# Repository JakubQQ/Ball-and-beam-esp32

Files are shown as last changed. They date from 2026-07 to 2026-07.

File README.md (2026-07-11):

# ESP32 Ball and Beam Control System

An autonomous ball-and-beam stabilization system designed, manufactured, and programmed completely from scratch. This project demonstrates the practical application of control theory, embedded systems programming, and rapid prototyping.

## Key Features
- **Control Feedback Loop:** Implemented a tuned **PID controller** for real-time ball position stabilization.
- **Signal Processing:** Integrated an **EMA (Exponential Moving Average) filter** to denoise the distance sensor data without introducing critical phase lag.
- **Hardware Platform:** Powered by a **ESP32** microcontroller driving a high-torque servo motor.
- **Mechanical Design:** Custom structural components designed from scratch in **Autodesk Inventor** and manufactured via 3D printing.

## 🛠️ Engineering Challenges & Solutions

### 1. Optical Sensing Geometry
The Time-of-Flight (ToF) laser sensor features a conical field of view. During initial testing, this led to signal loss and false readings. 
* **Solution:** Iteratively optimized the sensor's mounting angle, extended the physical length of the beam, and adjusted the ball diameter to maximize the reflected light returning to the receiver.

### 2. Sensor Noise Filtering
Raw data from the ToF sensor suffered from high-frequency noise, which caused the servo to jitter and destabilized the PID loop.
* **Solution:** Developed and deployed a digital EMA filter. This effectively smoothed out the noise while maintaining low latency, ensuring smooth and responsive control behavior.

## 📂 Repository Structure
- `/src` - Source code for ESP32 (`.ino` file)
- `/3DModels` - CAD models and `.stl` files for 3D printing

---
*Created as a personal project to bridge university theoretical knowledge with practical, hands-on engineering.*
Bez tytułu

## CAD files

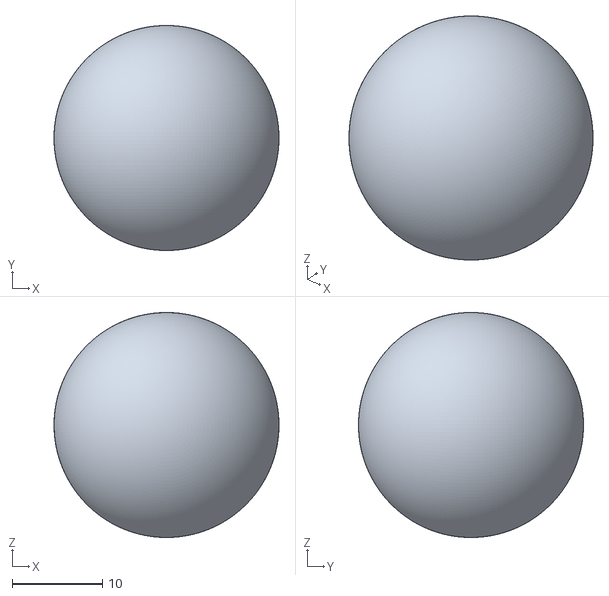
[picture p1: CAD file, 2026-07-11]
3Dmodels/ruchome.stl
25.0 x 25.0 x 25.0

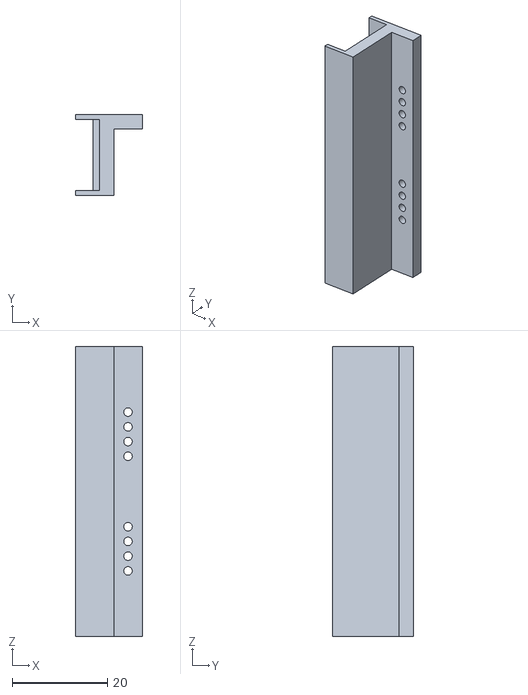
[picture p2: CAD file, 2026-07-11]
3Dmodels/czesc z silnikiem.stl
14.0 x 17.0 x 61.0

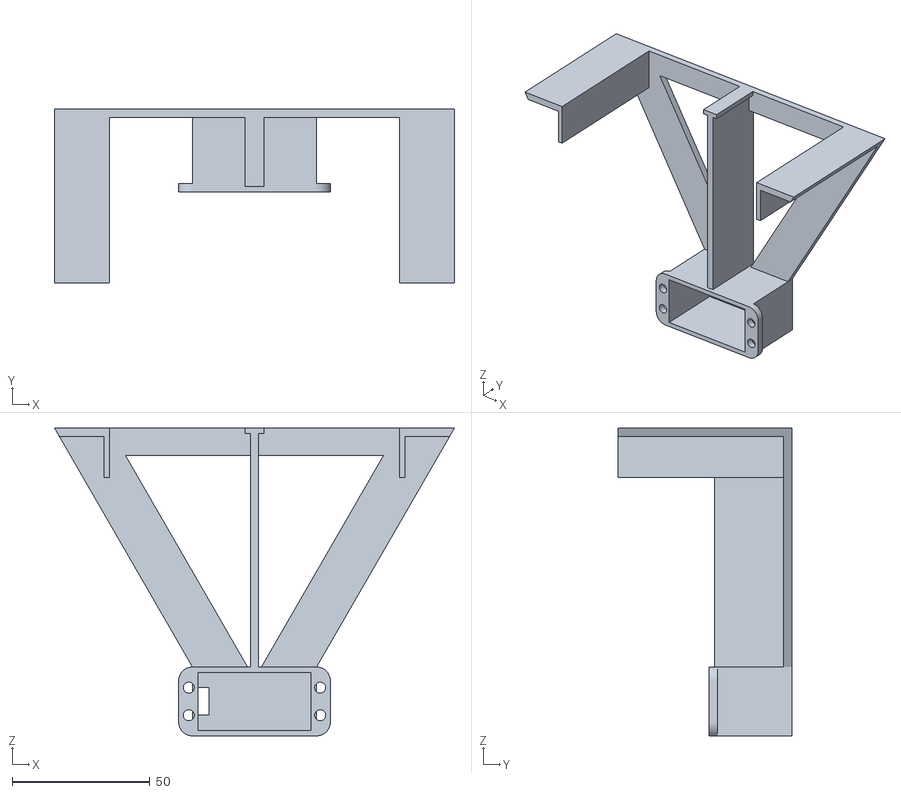
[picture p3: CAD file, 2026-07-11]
3Dmodels/ObudowaSerwo.stl
145.0 x 63.0 x 111.6

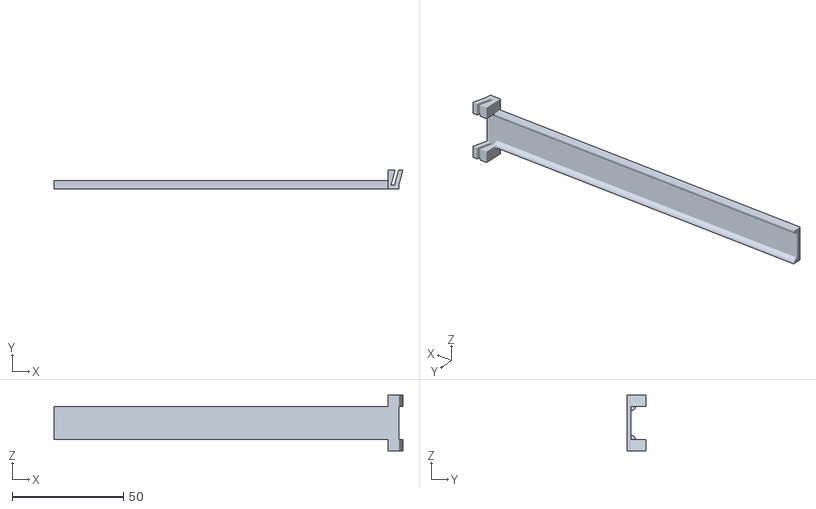
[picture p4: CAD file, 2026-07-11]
3Dmodels/Pochylnia15cm.stl
156.8 x 8.76 x 25.0

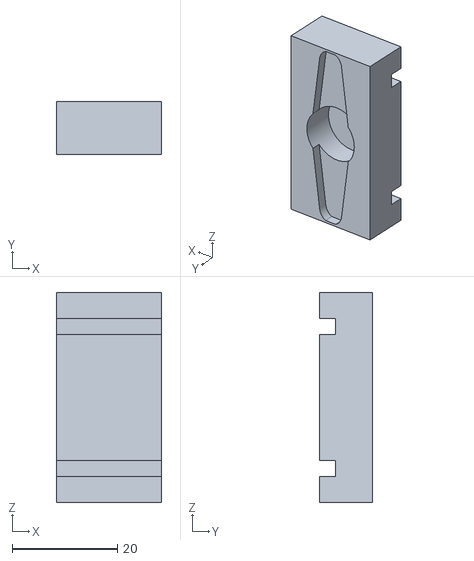
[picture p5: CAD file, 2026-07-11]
3Dmodels/OrczykFit2smigielka.stl
20.0 x 10.0 x 40.0

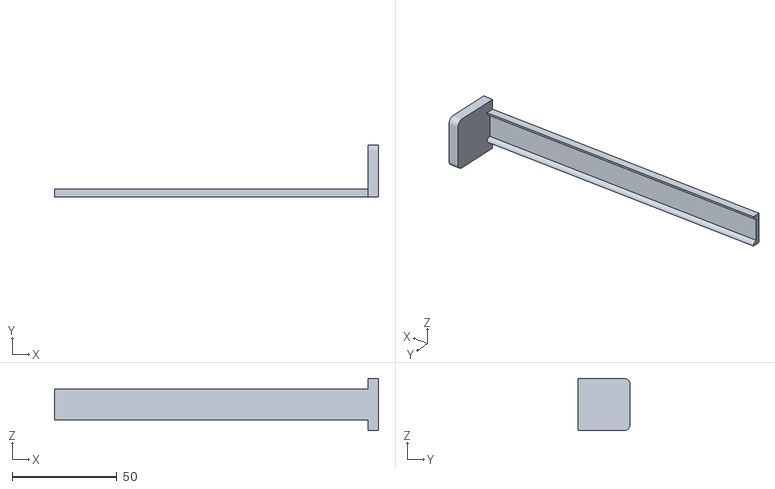
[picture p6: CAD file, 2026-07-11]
3Dmodels/PochylniaTyl15cm.stl
155.0 x 25.0 x 25.0

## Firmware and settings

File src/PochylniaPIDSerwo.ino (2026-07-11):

#include <ESP32Servo.h>
#include "Adafruit_VL53L0X.h"

Servo PochylniaSerwo;

Adafruit_VL53L0X lox = Adafruit_VL53L0X();
int licznik_petli = 0;
int wyslij = 0;
int pomiar = 0;
bool pisanie = false;

//EMA
float wartosc_poprzednia = 140.0;
float wartosc_obecna = 140.0;
float alpha = 0.2;

const int SerwoPin = 19;

int KatPochylenia = 1430; //O dziwo taki kąt powinien być idealnie płaski             Jeszcze dodatkowe obserwacje, te serwo reaguje na zmiany co 2 stopnie, nie wykrywa nieparzystych np 67 69
                        //1100 to jeden limit zanim się wykopyrtnie jedna strona
                        //1700 to limit w drugą stronę
int odleglosc_zadana = 140;    //Ignorować wartości powyżej 330mm i poniżej 35 to zaokrąglać jako min
                        //Minimalna wartość to 35 maksymalna 330
int Histereza = 15;
float odleglosc_rzeczywista = 140.0;
float odleglosc_poprzednia = 140.0;

//PID
float obecny_czas  = 0;
float poprzedni_czas = 0;
float dt = 0;
float uchyb = 0;
float uchyb_poprzedni = 0;
float suma_calkowania = 0;
float wynik_rozniczki = 0;
float sterowanie = 0;
float K = -0.3;
float Ti = 3;
float Td = 0.5;

int pomiar_odleglosci();
int PID(float,float);

void setup() {
  Serial.begin(9600);
  delay(1000);
  Serial.println("odpalanie espa");
  PochylniaSerwo.attach(SerwoPin);
  PochylniaSerwo.write(KatPochylenia);

  if(!lox.begin()) Serial.println("Nie znaleziono czujnika");
  VL53L0X_RangingMeasurementData_t measure;
  lox.rangingTest(&measure, false);
  if(measure.RangeStatus != 4) {
  wartosc_obecna = measure.RangeMilliMeter;
  }
}

unsigned long poprzedni_czas_czujnika = 0;
unsigned long obecny_czas_ms = 0;
const unsigned long okres_probkowania_ms = 30;

void loop() 
{
  obecny_czas_ms = millis();
  obecny_czas = micros();

  if(obecny_czas_ms - poprzedni_czas_czujnika >= okres_probkowania_ms)
  {
    dt = (obecny_czas - poprzedni_czas)/1000000;
    poprzedni_czas = obecny_czas;

    uchyb_poprzedni = uchyb;
    odleglosc_rzeczywista = pomiar_odleglosci();
    //Uchyb
    uchyb = odleglosc_zadana - odleglosc_rzeczywista;
    if(uchyb < 0 and uchyb > -5) uchyb = 0;
    if(uchyb > 0 and uchyb < 5) uchyb = 0;

    int wartosc_sterujaca = PID(uchyb,uchyb_poprzedni) + KatPochylenia;
    wartosc_sterujaca = constrain(wartosc_sterujaca,1100,1700);
    PochylniaSerwo.writeMicroseconds(wartosc_sterujaca);

    poprzedni_czas_czujnika = obecny_czas_ms;
  }
  //Serial.print(" | Obecne dt: "); Serial.println(dt,6);
}

int pomiar_odleglosci()
{
  int odleglosc = 0;

  VL53L0X_RangingMeasurementData_t measure;
  lox.rangingTest(&measure,false);
  odleglosc = measure.RangeMilliMeter;

  if(odleglosc >= 330) odleglosc = 330;
  if(odleglosc <= 35) odleglosc = 35;

  wartosc_obecna = alpha*odleglosc + (1.0 - alpha) * wartosc_poprzednia;
  wartosc_poprzednia = wartosc_obecna;

  wyslij++;
  if(wyslij == 25)
  {
    wyslij = 0;

    Serial.print("Odległośc: "); 
    if (measure.RangeStatus != 4)
    {
      Serial.print(measure.RangeMilliMeter);
      Serial.print(" mm");
      Serial.print(" | Odleglosc EMA: ");
      Serial.println(wartosc_obecna);
    } else {
      Serial.println("Poza zasięgiem");
    }
    pisanie = true;
  }

  return wartosc_obecna;
}

int PID(float uchyb, float uchyb_poprzedni)
{
  //Całkowanie
  suma_calkowania = uchyb*dt + suma_calkowania;

  float limit_calki = 150;
  suma_calkowania = constrain(suma_calkowania,-limit_calki,limit_calki);
  //Różniczkowanie
  wynik_rozniczki = (uchyb - uchyb_poprzedni)/dt;
  sterowanie = K*(uchyb + 1.0/Ti*suma_calkowania + Td*wynik_rozniczki);
  return sterowanie;
}
